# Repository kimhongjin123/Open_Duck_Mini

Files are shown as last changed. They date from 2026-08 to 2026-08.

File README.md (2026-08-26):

# Open Duck Mini v2

<table>
  <tr>
    <td> </td>
    <td> </td>
    <td> </td>
   </tr> 
</table>

## Fork addition: MiniDuck IO Shield

This fork adds a custom Raspberry Pi Zero 2 W I/O shield designed for the Open Duck Mini prototype. The addition includes the complete KiCad 9 project, connector and GPIO mapping, BOM, schematic PDF, prototype manufacturing outputs, photos, and a hardware demonstration video.

**[Open the MiniDuck IO Shield documentation](hardware/miniduck-io-shield/README.md)**

<p align="center">
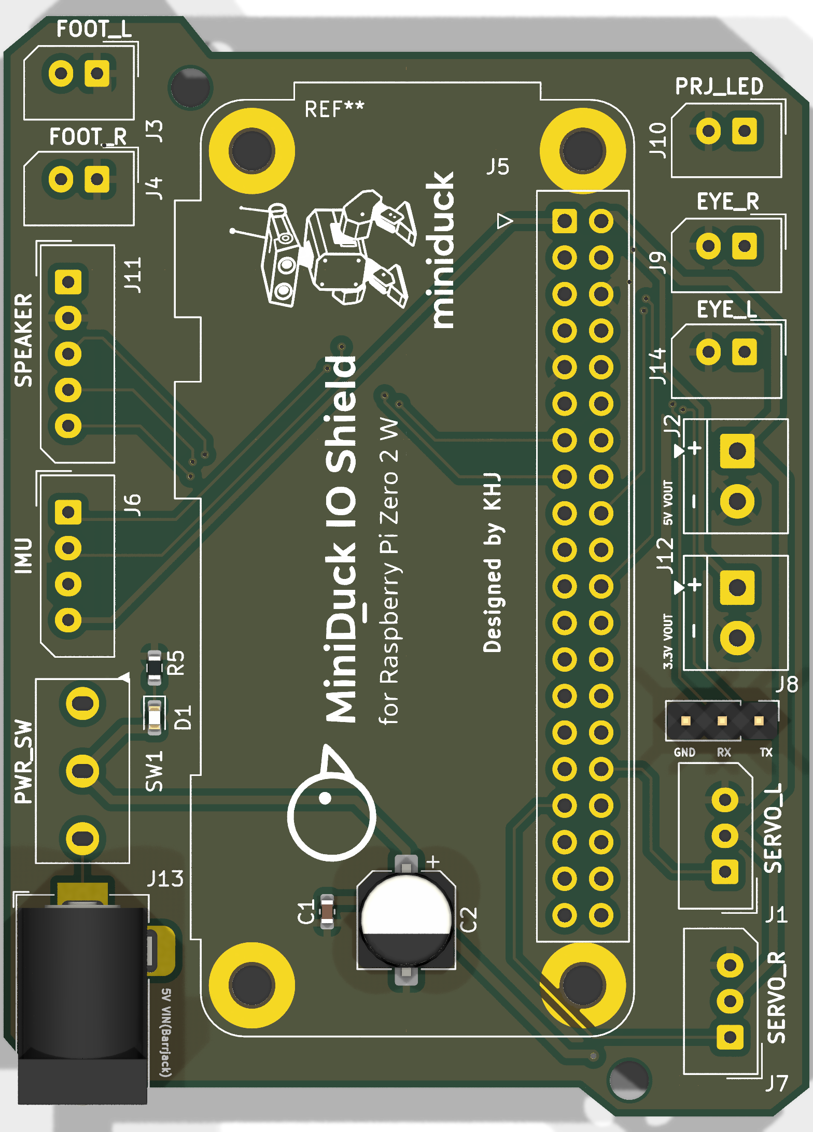
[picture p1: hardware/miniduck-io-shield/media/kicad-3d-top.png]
MiniDuck IO Shield top render
  
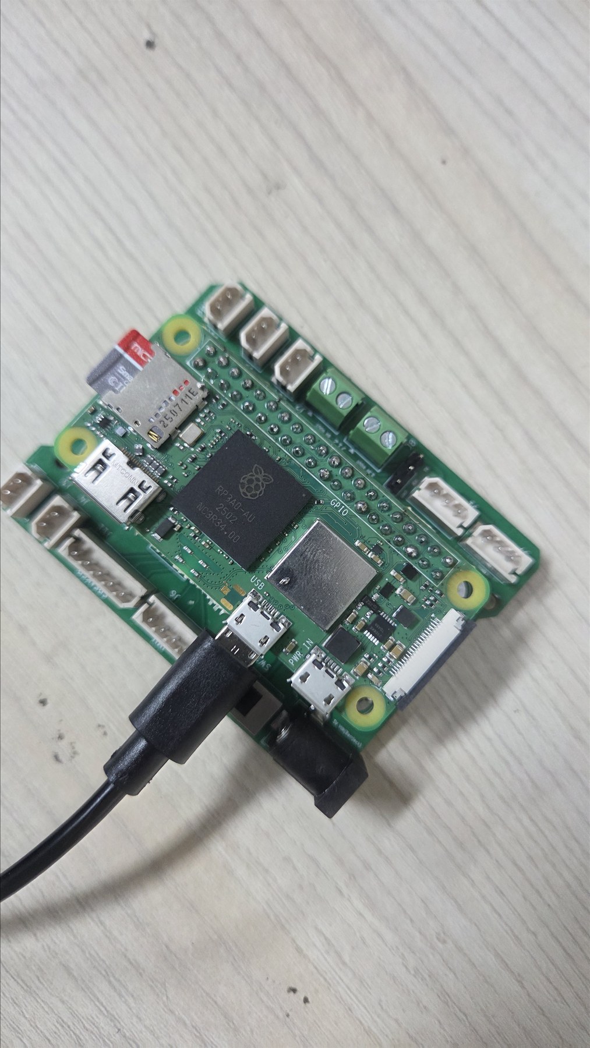
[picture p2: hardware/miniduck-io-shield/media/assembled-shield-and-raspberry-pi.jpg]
Assembled MiniDuck IO Shield with Raspberry Pi Zero 2 W
  
</p>

> [!IMPORTANT]
> This shield is a community hardware addition maintained in this fork; it is not part of the upstream Open Duck Mini design. Review the documented prototype warnings before fabrication.

We are making a miniature version of the BDX Droid by Disney. It is about 42 centimeters tall with its legs extended.
The full BOM cost should be under $400 !

This repo is kind of a hub where we centralize all resources related to this project. This is a working repo, so there are a lot of undocumented scripts :) We'll try to clean things up at some point.

# State of sim2real

https://github.com/user-attachments/assets/58721d0f-2f95-4088-8900-a5d02f41bba7

https://github.com/user-attachments/assets/4129974a-9d97-4651-9474-c078043bb182

https://github.com/user-attachments/assets/a0afcd38-15d8-40c6-8171-a619107406b8

# Updates

> Update 02/04/2024: You can try two policies we trained : [this one](BEST_WALK_ONNX.onnx) and [this one](BEST_WALK_ONNX_2.onnx)
> Run with the following arguments :
> python v2_rl_walk_mujoco.py --onnx_model_path ~/BEST_WALK_ONNX_2.onnx

> Update 15/03/2025: join our discord server to get help or show us your duck :) https://discord.gg/UtJZsgfQGe

> Update 07/02/2025: Big progress on sim2real, see videos above :)

> Update 24/02/2025: Working hard on sim2real ! 

> Update 07/02/2025 : We are writing documentation on the go, but the design and BOM should not change drastically. Still missing the "expression" features, but they can be added after building the robot!

> Update 22/01/2025 : The mechanical design is pretty much finalized (fixing some mistakes here and there). The current version does not include all the "expression" features we want to include in the final robot (LEDs for the eyes, a camera, a speaker and a microphone). We are now working on making it walk with reinforcement learning !

# Community 

duck_collage

Join our discord community ! https://discord.gg/UtJZsgfQGe

# CAD

https://cad.onshape.com/documents/64074dfcfa379b37d8a47762/w/3650ab4221e215a4f65eb7fe/e/0505c262d882183a25049d05

See [this document](docs/prepare_robot.md) for getting from a onshape design to a simulated robot in MuJoCo (Warning, outdated. Has not been updated in a while)

# RL stuff

We are switching to Mujoco Playground, see this [repo](https://github.com/apirrone/Open_Duck_Playground)

https://github.com/user-attachments/assets/037a1790-7ac1-4140-b154-2c901d20d5f5

## Reference motion generation for imitation learning 

https://github.com/user-attachments/assets/4cb52e17-99a5-47a8-b841-4141596b7afb

See [this repo](https://github.com/apirrone/Open_Duck_reference_motion_generator)

## Actuator identification 

We used Rhoban's [BAM](https://github.com/Rhoban/bam)

# BOM

https://docs.google.com/spreadsheets/d/1gq4iWWHEJVgAA_eemkTEsshXqrYlFxXAPwO515KpCJc/edit?usp=sharing

Chinese: https://zihao-ai.feishu.cn/wiki/AfAtw69vRigXaRk5UkbcrAiLnJw?from=from_copylink

# Build Guide

> New : you can now use the Tnkr guide ! https://tnkr.ai/explore/docs/open-duck-mini/open-duck-mini-v2#home

Chinese: https://zihao-ai.feishu.cn/wiki/space/7488517034406625281

## Print Guide

See [print_guide](docs/print_guide.md).

## Assembly Guide

See [assembly guide (incomplete)](docs/assembly_guide.md).

# Embedded runtime

This repo contains the code to run the policies on the onboard computer (Raspberry pi zero 2w) https://github.com/apirrone/Open_Duck_Mini_Runtime

# Training your own policies

If you want to train your own policies, and contribute to making the ducks walk nicely, see [this document](docs/sim2real.md)

> Thanks a lot to HuggingFace and Pollen Robotics for sponsoring this project !

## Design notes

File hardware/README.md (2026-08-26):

# Hardware additions

This directory contains hardware developed in this fork and kept separate from the upstream Open Duck Mini files.

- [MiniDuck IO Shield](miniduck-io-shield/README.md) - Raspberry Pi Zero 2 W carrier and I/O breakout for the robot prototype.

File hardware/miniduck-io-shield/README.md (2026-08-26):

# MiniDuck IO Shield

A two-layer Raspberry Pi Zero 2 W shield that consolidates power distribution and the Open Duck Mini prototype's servo, foot-switch, IMU, speaker, UART, and LED connections.

MiniDuck IO Shield top render

This is a fork-specific community hardware addition, designed by KHJ and kept separate from the upstream Open Duck Mini design. The board has been fabricated, assembled with a Raspberry Pi Zero 2 W, and exercised on the robot prototype shown below.

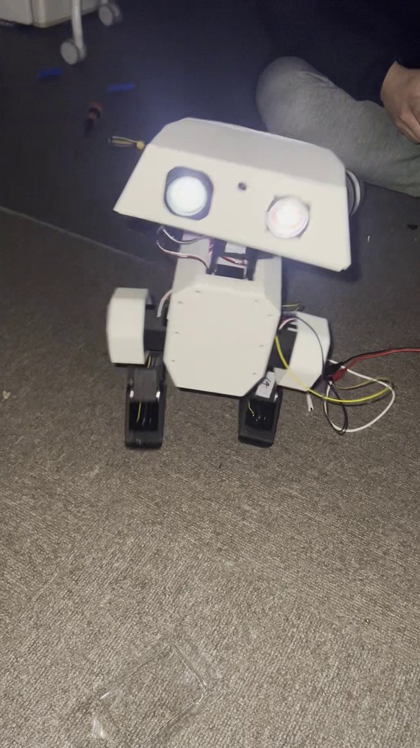
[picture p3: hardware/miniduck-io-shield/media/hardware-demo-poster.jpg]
Open Duck Mini hardware demonstration


The linked demonstration is a 46.9-second, 1080 x 1920 HEVC MP4. A [five-frame contact sheet](media/hardware-demo-contact-sheet.jpg) is also available for quick viewing.

## Board summary

| Item | Detail |
| --- | --- |
| Controller | Raspberry Pi Zero 2 W, 40-pin GPIO header |
| PCB | 2 layers, 1.6 mm nominal thickness |
| Outline | Approximately 56.0 x 76.5 mm bounding box |
| Input power | 5 V barrel-jack input through onboard slide switch |
| Power outputs | 5 V and 3.3 V screw-terminal breakouts |
| Robot I/O | 2 servo, 2 foot-switch, I2C IMU, I2S speaker, UART, and 3 LED outputs |
| Main connector families | 2.50 mm Molex SPOX, 3.50 mm screw terminals, 2.54 mm pin/IDC headers |
| Design tool | KiCad 9; outputs regenerated with KiCad 9.0.4 |
| Status | Fabricated and assembled prototype; see validation notes before reuse |

## Repository contents

| Path | Contents |
| --- | --- |
| [`kicad/`](kicad/) | Editable schematic, PCB, and project files |
| [`CONNECTORS.md`](CONNECTORS.md) | Connector pinout and Raspberry Pi GPIO mapping |
| [`docs/bom.csv`](docs/bom.csv) | BOM exported from the schematic |
| [`docs/schematic.pdf`](docs/schematic.pdf) | Single-page schematic for quick review |
| [`docs/drc-report.json`](docs/drc-report.json) | KiCad PCB rule-check report |
| [`docs/erc-report.json`](docs/erc-report.json) | KiCad schematic rule-check report |
| [`manufacturing/`](manufacturing/) | Prototype Gerbers, drill files, maps, and a vendor-upload ZIP |
| [`media/`](media/) | Renders, PCB/layout photos, assembly photos, robot photo, and demo video |

The original KiCad basename, `miniduc_shild`, is preserved so the project opens without disrupting its existing file relationships. Local KiCad state, caches, and automatic backups are intentionally excluded.

## Photos

| Fabricated board | Assembled shield |
| --- | --- |
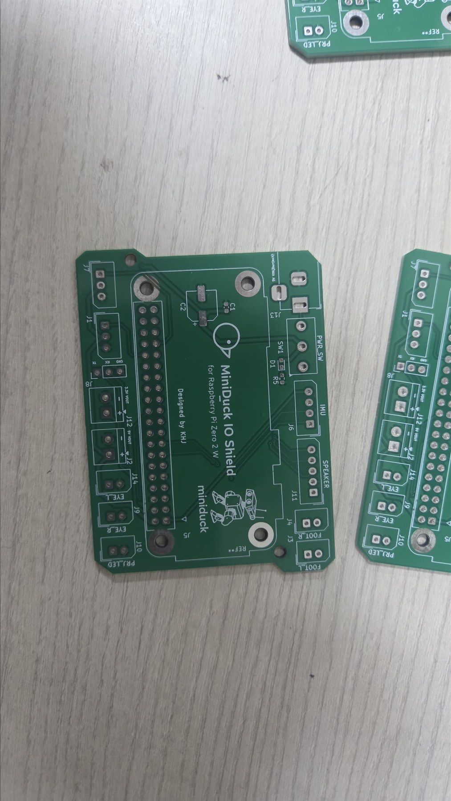
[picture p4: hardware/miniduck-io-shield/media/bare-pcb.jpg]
Fabricated MiniDuck IO Shield
|  | Assembled shield and Raspberry Pi Zero 2 W |

| PCB layout | Robot prototype |
| --- | --- |
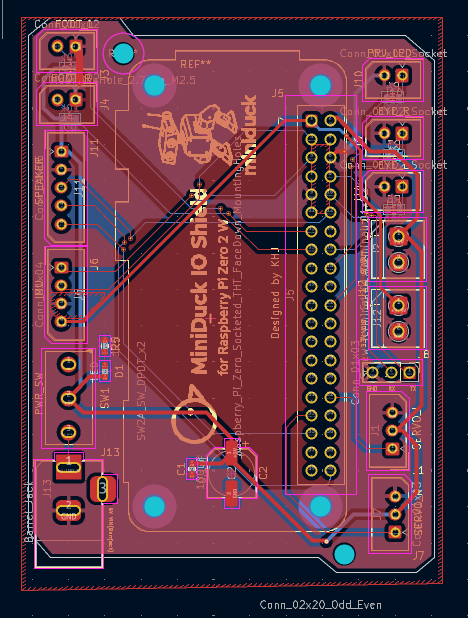
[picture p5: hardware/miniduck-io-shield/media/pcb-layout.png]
MiniDuck IO Shield PCB layout
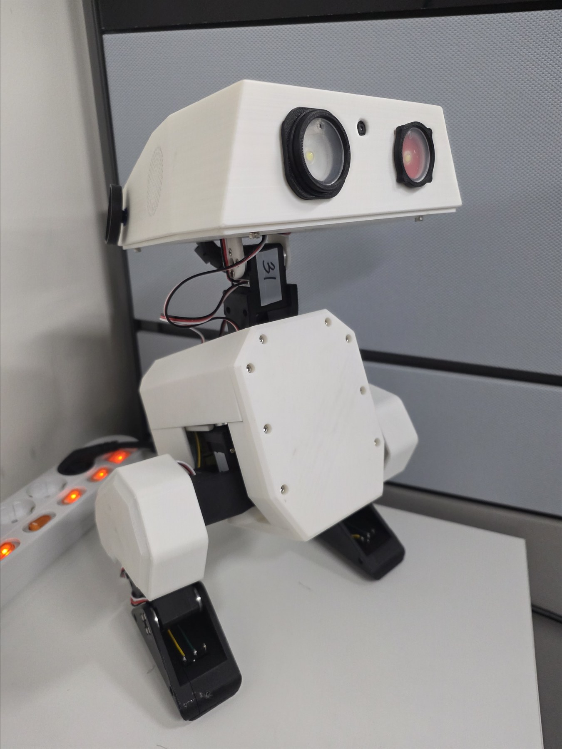
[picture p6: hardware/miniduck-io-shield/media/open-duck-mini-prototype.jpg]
Open Duck Mini robot prototype
|  |  |

## Important prototype notes

- The three LED connector silkscreen labels do not match the electrical nets. Follow the actual-net mapping in [`CONNECTORS.md`](CONNECTORS.md), not the nearby label alone.
- KiCad reports no error-severity ERC/DRC items, but it does report warnings. The exact counts and categories are recorded in [`VALIDATION.md`](VALIDATION.md).
- R1 is a 10 kOhm resistor assigned to a `C_0603_1608Metric` library footprint. The land pattern is 0603-sized, but the library assignment should be corrected in a future revision.
- The custom slide-switch footprint name may not exist in another user's local library. Its placed footprint geometry is embedded in the PCB file.
- The manufacturing package is a reproducible snapshot of this fabricated prototype, not a claim that the design has passed an independent production review.

## Opening and regenerating

1. Open `kicad/miniduc_shild.kicad_pro` in KiCad 9.
2. Review the schematic and PCB against the intended wiring and connector orientation.
3. Run ERC and DRC locally and inspect every warning.
4. Regenerate Gerbers and drill files from the reviewed PCB before ordering a revised batch.

This folder follows the repository's root [Apache-2.0 license](../../LICENSE).

## 한국어 요약

이 폴더는 Raspberry Pi Zero 2 W 기반 Open Duck Mini용 I/O 실드보드 작업을 정리한 것입니다. KiCad 원본, 핀맵, BOM, 회로도 PDF, 시제품 제조 파일, 제작·조립 사진과 구동 영상을 포함합니다. 현재 파일은 실제 제작된 프로토타입 기록이며, LED 커넥터 실크 인쇄와 실제 GPIO 연결이 서로 다르므로 재사용하거나 재발주하기 전에 반드시 [`CONNECTORS.md`](CONNECTORS.md)와 [`VALIDATION.md`](VALIDATION.md)를 확인해야 합니다.

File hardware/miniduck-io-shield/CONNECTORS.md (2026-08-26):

# Connector and GPIO map

Pin numbers below come from the KiCad schematic/netlist. Verify physical orientation from the footprint's pin-1 marker before connecting hardware.

## External connectors

| Ref | Board function / nearby silkscreen | Pin mapping |
| --- | --- | --- |
| J1 | SERVO_L | 1: GPIO12 / servo L signal; 2: +5 V; 3: GND |
| J2 | 5V VOUT | 1: +5 V; 2: GND |
| J3 | FOOT_L | 1: GND; 2: GPIO22 / foot L input |
| J4 | FOOT_R | 1: GND; 2: GPIO27 / foot R input |
| J5 | Raspberry Pi 40-pin header | See the GPIO table below |
| J6 | IMU | 1: GPIO3 / I2C SCL1; 2: GPIO2 / I2C SDA1; 3: GND; 4: +3.3 V |
| J7 | SERVO_R | 1: GPIO13 / servo R signal; 2: +5 V; 3: GND |
| J8 | UART | 1: GPIO15 / UART RX; 2: GPIO14 / UART TX; 3: GND |
| J9 | Nearby silkscreen: EYE_R | 1: through R3 (220 Ohm) to GPIO24 / LED_L; 2: GND |
| J10 | Nearby silkscreen: PRJ_LED | 1: through R4 (220 Ohm) to GPIO25 / LED_R; 2: GND |
| J11 | SPEAKER | 1: +5 V; 2: GND; 3: GPIO18 / I2S BCLK; 4: GPIO21 / I2S DOUT; 5: GPIO19 / I2S LRCLK |
| J12 | 3.3V VOUT | 1: +3.3 V; 2: GND |
| J13 | 5V VIN barrel jack | 1: switched 5 V input through SW1; 2: GND |
| J14 | Nearby silkscreen: EYE_L | 1: through R6 (220 Ohm) to GPIO23 / LED_PRJ; 2: GND |

> [!CAUTION]
> J9, J10, and J14 have a confirmed silkscreen-to-net mismatch in this revision. Electrically, J9 is LED_L, J10 is LED_R, and J14 is LED_PRJ. Use the electrical mapping above.

## Raspberry Pi header signals used

| Physical pin | Net / function |
| ---: | --- |
| 1 | +3.3 V |
| 2 | +5 V |
| 3 | GPIO2 / I2C SDA1 |
| 5 | GPIO3 / I2C SCL1 |
| 6 | GND |
| 8 | GPIO14 / UART TX |
| 9 | GND |
| 10 | GPIO15 / UART RX |
| 12 | GPIO18 / I2S BCLK |
| 13 | GPIO27 / foot R |
| 15 | GPIO22 / foot L |
| 16 | GPIO23 / projector LED |
| 18 | GPIO24 / left-eye LED |
| 22 | GPIO25 / right-eye LED |
| 32 | GPIO12 / servo L |
| 33 | GPIO13 / servo R |
| 35 | GPIO19 / I2S LRCLK |
| 40 | GPIO21 / I2S DOUT |

All other J5 positions are unconnected in the shield schematic.

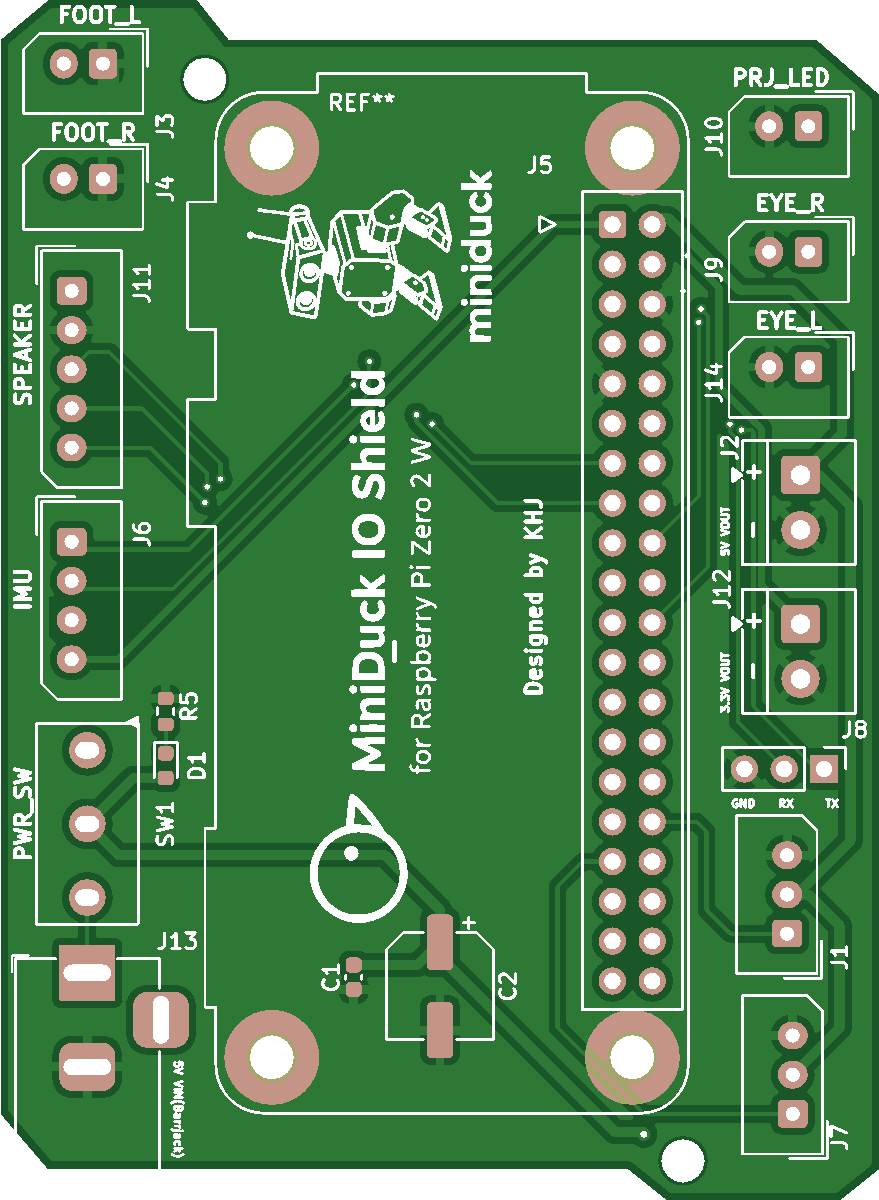
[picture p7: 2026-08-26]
hardware/miniduck-io-shield/media/pcb-render.png

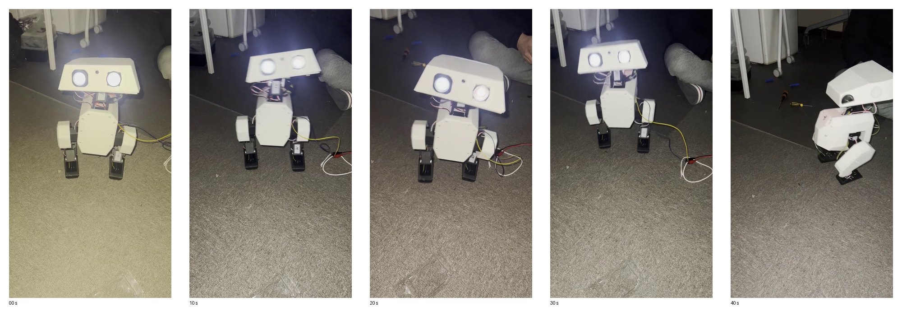
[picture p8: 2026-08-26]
hardware/miniduck-io-shield/media/hardware-demo-contact-sheet.jpg

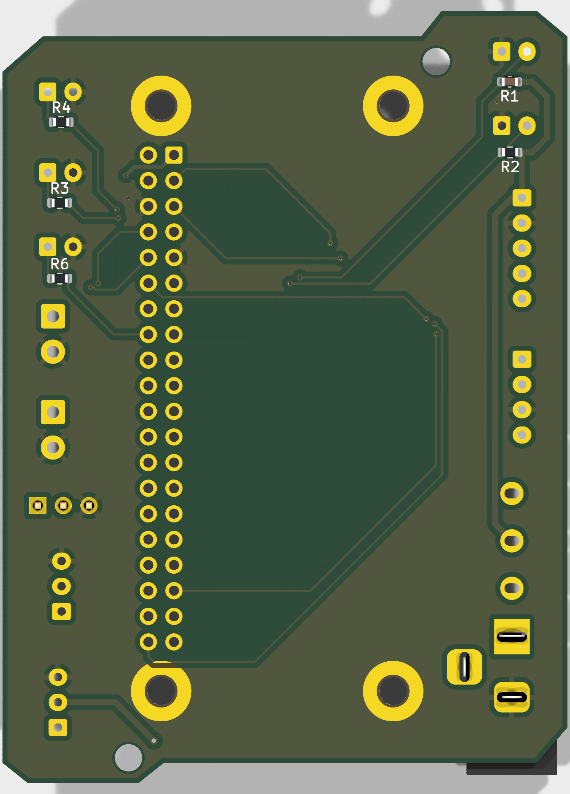
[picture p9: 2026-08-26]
hardware/miniduck-io-shield/media/kicad-3d-bottom.png

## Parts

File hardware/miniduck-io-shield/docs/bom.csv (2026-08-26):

Refs | Value | Footprint | Qty | DNP
C1 | 0.1uF | Capacitor_SMD:C_0603_1608Metric | 1
C2 | 100uF | Capacitor_SMD:CP_Elec_6.3x5.3 | 1
D1 | LED | LED_SMD:LED_0603_1608Metric | 1
J1 | Servo_L | Connector_Molex:Molex_SPOX_5267-03A_1x03_P2.50mm_Vertical | 1
J2,J12 | Screw_Terminal_01x02 | TerminalBlock_4Ucon:TerminalBlock_4Ucon_1x02_P3.50mm_Horizontal | 2
J3,J4 | Conn_01x02 | Connector_Molex:Molex_SPOX_5267-02A_1x02_P2.50mm_Vertical | 2
J5 | Conn_02x20_Odd_Even | Connector_IDC:IDC-Header_2x20_P2.54mm_Latch6.5mm_Vertical | 1
J6 | Conn_01x04 | Connector_Molex:Molex_SPOX_5267-04A_1x04_P2.50mm_Vertical | 1
J7 | Conn_01x03 | Connector_Molex:Molex_SPOX_5267-03A_1x03_P2.50mm_Vertical | 1
J8 | Conn_01x03 | Connector_PinHeader_2.54mm:PinHeader_1x03_P2.54mm_Vertical | 1
J9,J10,J14 | Conn_01x02_Socket | Connector_Molex:Molex_SPOX_5267-02A_1x02_P2.50mm_Vertical | 3
J11 | Conn_01x05 | Connector_Molex:Molex_SPOX_5267-05A_1x05_P2.50mm_Vertical | 1
J13 | Barrel_Jack | Connector_BarrelJack:BarrelJack_Horizontal | 1
R1 | 10k | Capacitor_SMD:C_0603_1608Metric | 1
R2 | 10k | Resistor_SMD:R_0603_1608Metric | 1
R3,R4,R6 | 220 | Resistor_SMD:R_0603_1608Metric | 3
R5 | 120 | Resistor_SMD:R_0603_1608Metric | 1
SW1 | SW2A_SW_DPDT_x2 | wowmecha:SW_Slide_SPDT_PBS110G | 1

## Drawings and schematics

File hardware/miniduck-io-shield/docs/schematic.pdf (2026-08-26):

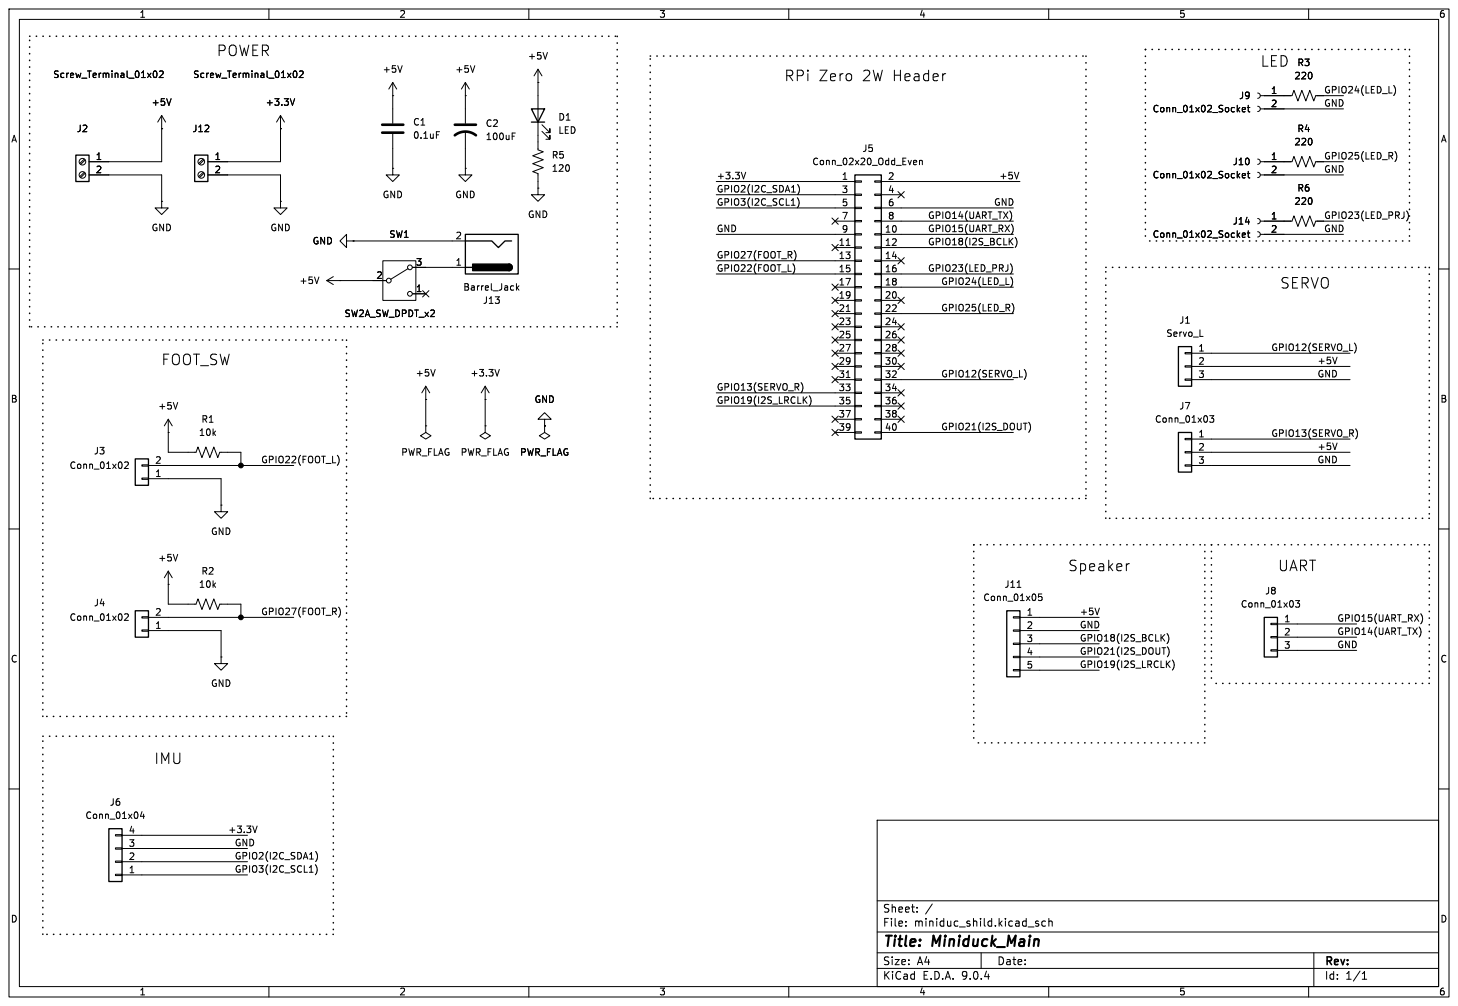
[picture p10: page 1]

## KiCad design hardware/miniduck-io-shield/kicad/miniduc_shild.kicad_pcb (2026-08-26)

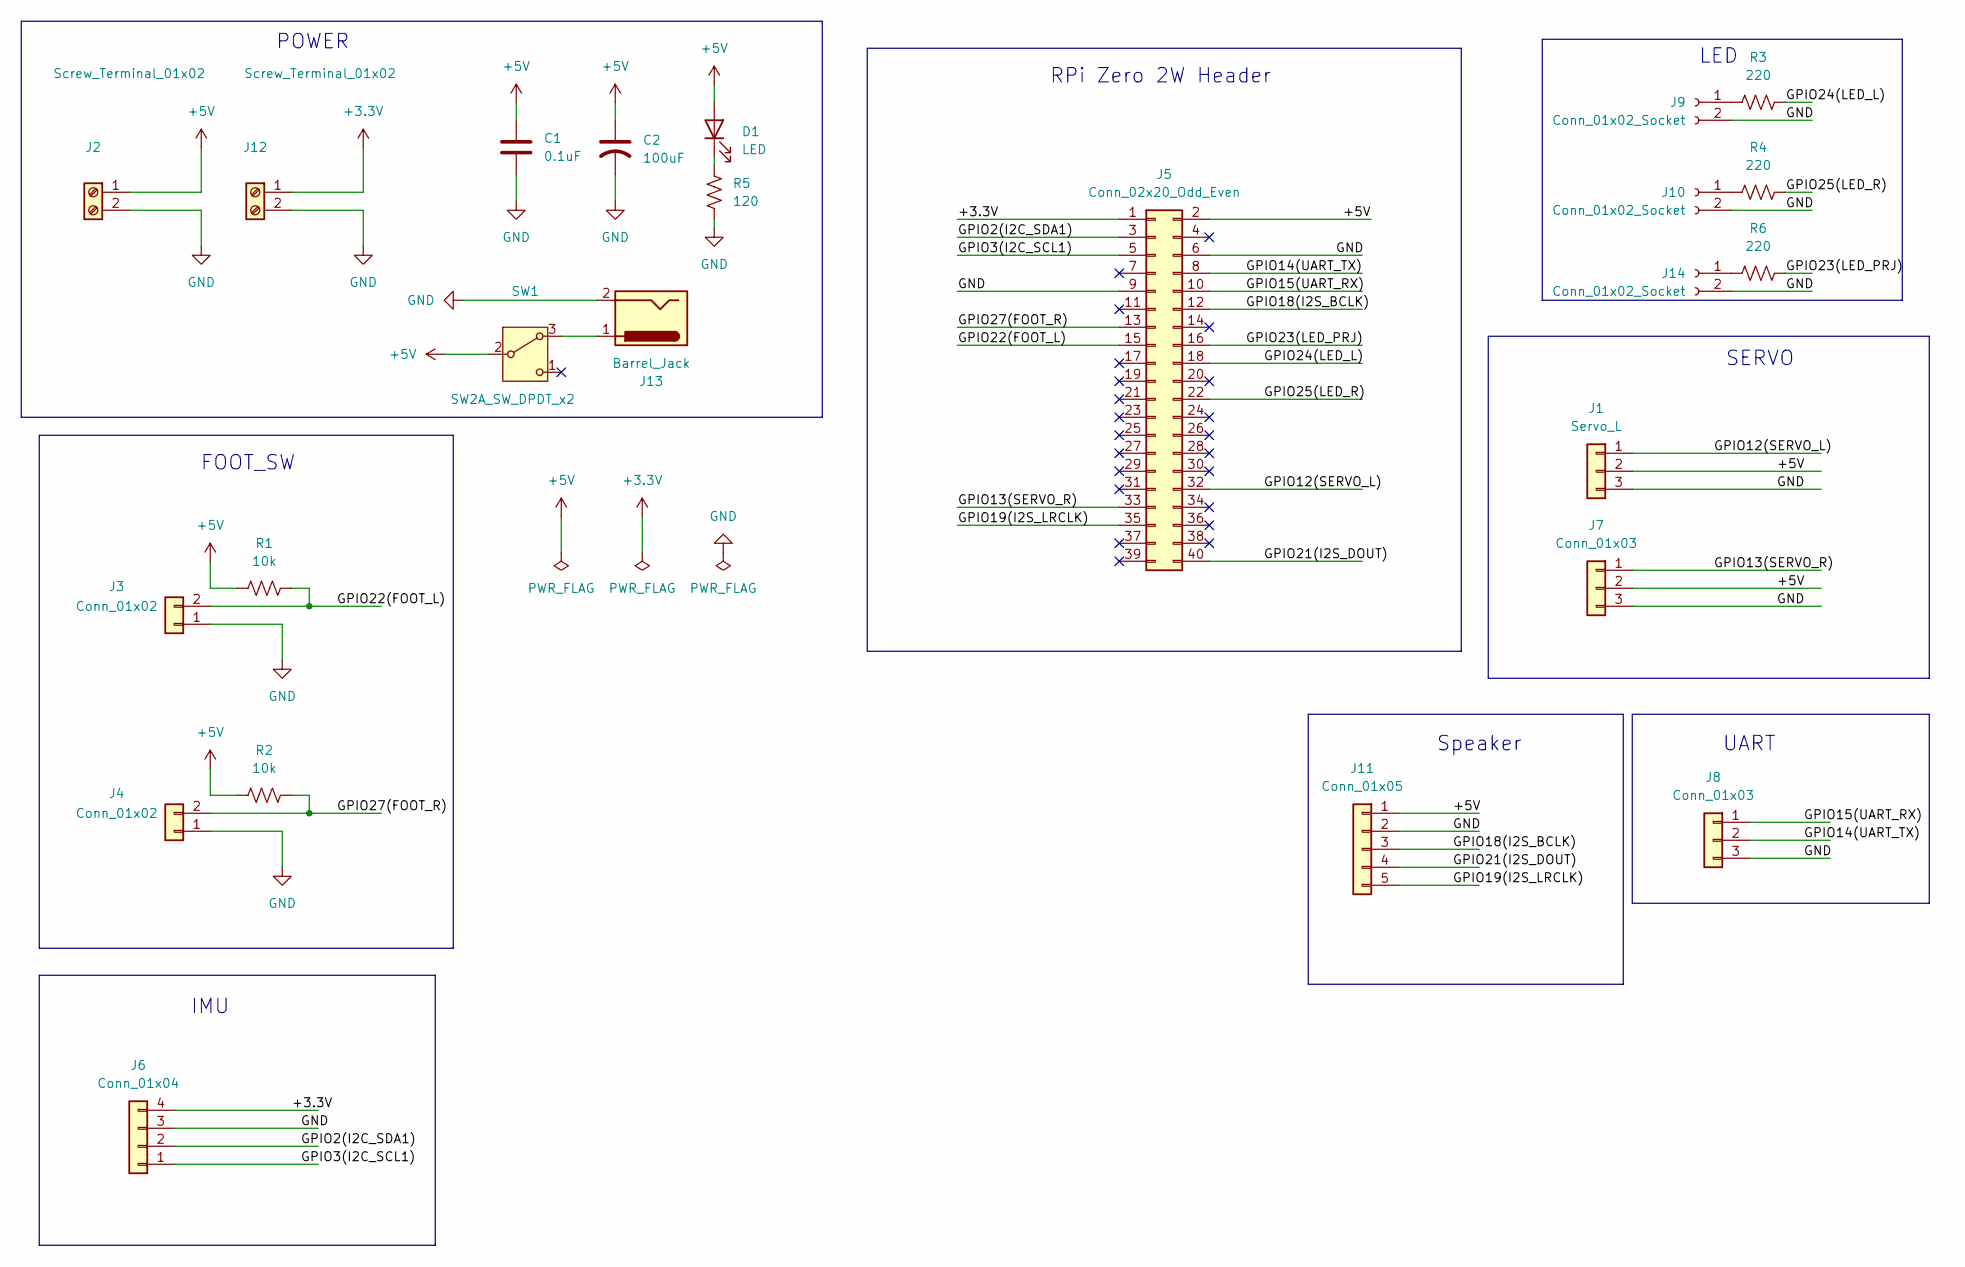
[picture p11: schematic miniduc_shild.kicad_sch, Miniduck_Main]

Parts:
C1: 0.1uF; C_0603_1608Metric
C2: 100uF; CP_Elec_6.3x5.3
D1: LED; LED_0603_1608Metric
J1: Servo_L; Molex_SPOX_5267-03A_1x03_P2.50mm_Vertical
J2, J12: Screw_Terminal_01x02; TerminalBlock_4Ucon_1x02_P3.50mm_Horizontal
J3, J4: Conn_01x02; Molex_SPOX_5267-02A_1x02_P2.50mm_Vertical
J5: Conn_02x20_Odd_Even; IDC-Header_2x20_P2.54mm_Latch6.5mm_Vertical
J6: Conn_01x04; Molex_SPOX_5267-04A_1x04_P2.50mm_Vertical
J7: Conn_01x03; Molex_SPOX_5267-03A_1x03_P2.50mm_Vertical
J8: Conn_01x03; PinHeader_1x03_P2.54mm_Vertical
J9, J10, J14: Conn_01x02_Socket; Molex_SPOX_5267-02A_1x02_P2.50mm_Vertical
J11: Conn_01x05; Molex_SPOX_5267-05A_1x05_P2.50mm_Vertical
J13: Barrel_Jack; BarrelJack_Horizontal
R1: 10k; C_0603_1608Metric
R2: 10k; R_0603_1608Metric
R3, R4, R6: 220; R_0603_1608Metric
R5: 120; R_0603_1608Metric
SW1: SW2A_SW_DPDT_x2; SW_Slide_SPDT_PBS110G

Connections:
+3.3V: J5.1, J6.4, J12.1
+5V: C1.2, C2.1, D1.2 (A), J1.2, J2.1, J5.2, J7.2, J11.1, R1.1, R2.1, SW1.2 (B)
/GPIO2(I2C_SDA1): J5.3, J6.2
/GPIO3(I2C_SCL1): J5.5, J6.1
/GPIO12(SERVO_L): J1.1, J5.32
/GPIO13(SERVO_R): J5.33, J7.1
/GPIO14(UART_TX): J5.8, J8.2
/GPIO15(UART_RX): J5.10, J8.1
/GPIO18(I2S_BCLK): J5.12, J11.3
/GPIO19(I2S_LRCLK): J5.35, J11.5
/GPIO21(I2S_DOUT): J5.40, J11.4
/GPIO22(FOOT_L): J3.2, J5.15, R1.2
/GPIO23(LED_PRJ): J5.16, R6.2
/GPIO24(LED_L): J5.18, R3.2
/GPIO25(LED_R): J5.22, R4.2
/GPIO27(FOOT_R): J4.2, J5.13, R2.2
GND: C1.1, C2.2, J1.3, J2.2, J3.1, J4.1, J5.6, J5.9, J6.3, J7.3, J8.3, J9.2, J10.2, J11.2, J12.2, J13.2, J14.2, R5.2
unnamed: D1.1 (K), R5.1
unnamed: J9.1, R3.1
unnamed: J10.1, R4.1
unnamed: J14.1, R6.1
unnamed: J13.1, SW1.3 (A)

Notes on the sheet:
POWER
UART
RPi Zero 2W Header
FOOT_SW
LED
IMU
SERVO
Speaker

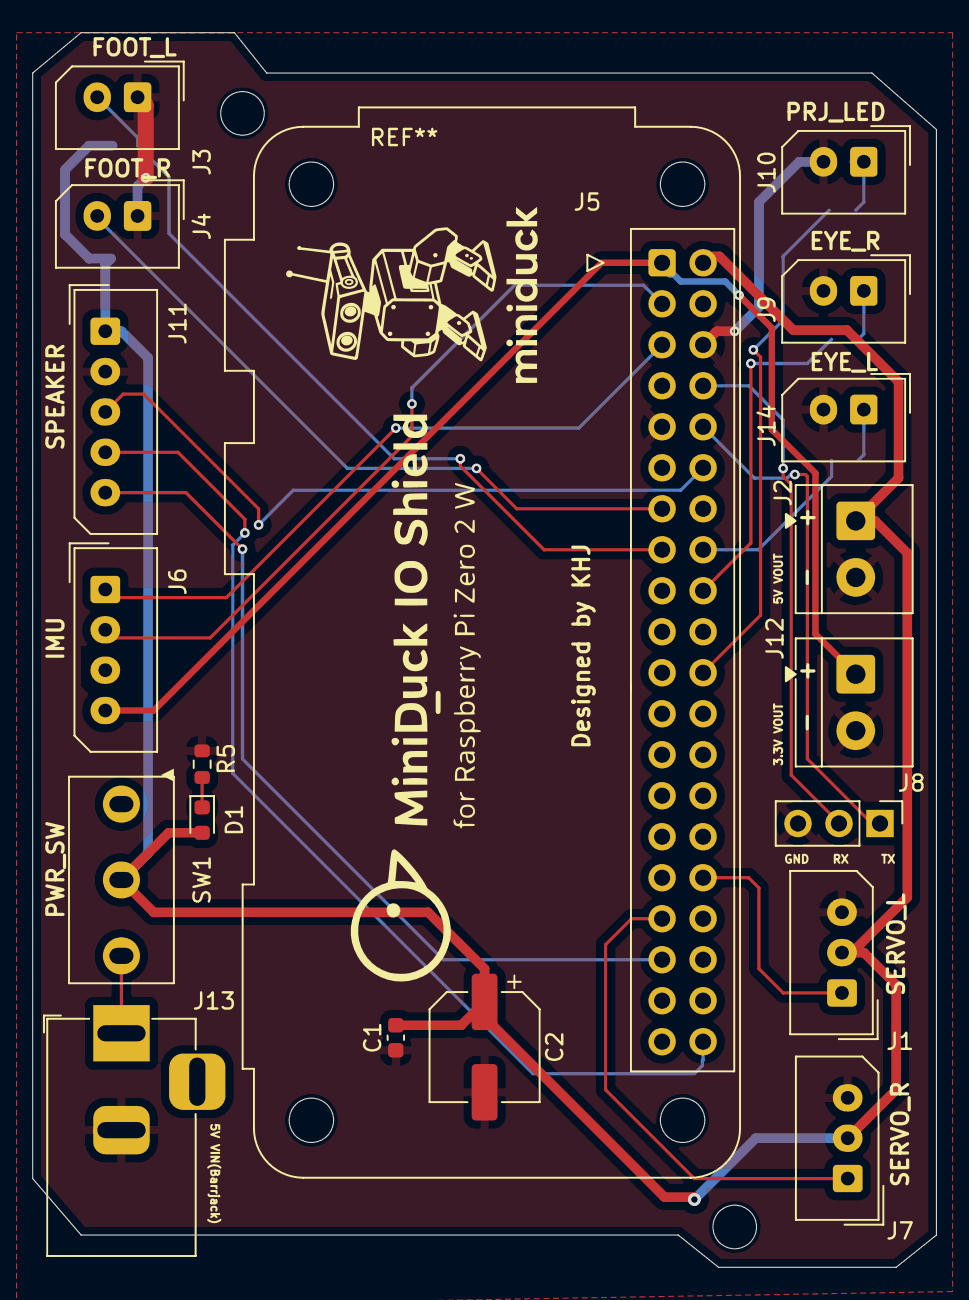
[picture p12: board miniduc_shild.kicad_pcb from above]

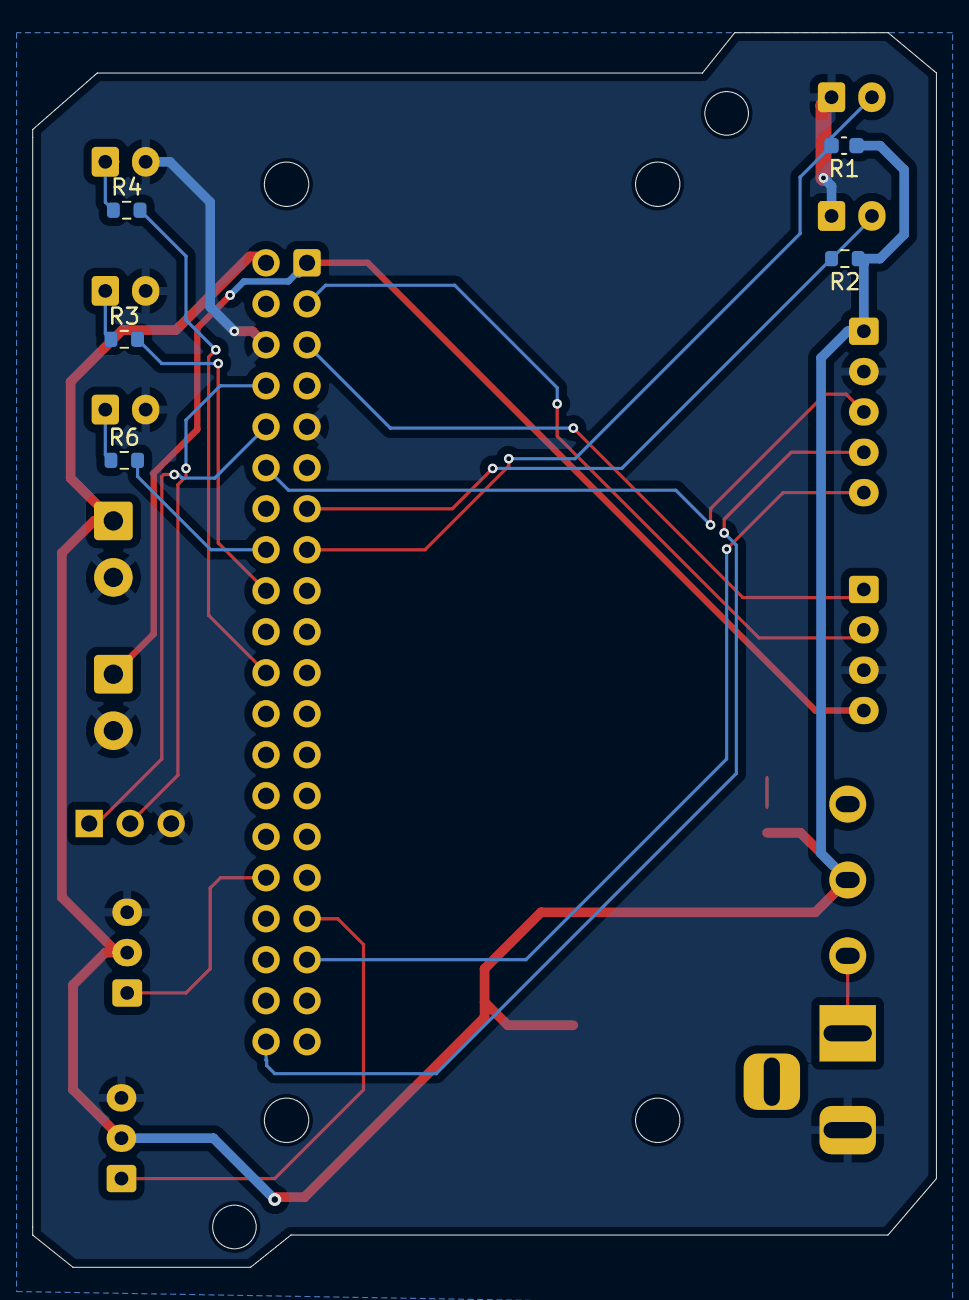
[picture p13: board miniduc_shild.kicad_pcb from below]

Board: 2 copper layers, 56.0 x 76.5 mm, 26 parts (5 on the bottom side), 22 nets.

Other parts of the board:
-: LOGO
Designed by KHJ: LOGO

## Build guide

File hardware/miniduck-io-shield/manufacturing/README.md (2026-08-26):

# Prototype manufacturing outputs

These files were regenerated from `../kicad/miniduc_shild.kicad_pcb` with KiCad CLI 9.0.4.

- [`gerbers/`](gerbers/) contains front/back copper, mask, paste, silkscreen, board outline, Gerber job file, PTH/NPTH drills, and drill maps.
- [`miniduck-io-shield-gerbers.zip`](miniduck-io-shield-gerbers.zip) packages the same set for convenient vendor upload.

The board is a fabricated prototype with documented DRC warnings. Read [`../VALIDATION.md`](../VALIDATION.md) and verify the Gerber preview, stack-up, drill sizes, connector orientation, and vendor rules before placing an order.

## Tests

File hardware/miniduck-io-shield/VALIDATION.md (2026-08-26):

# Validation record

The source snapshot was checked and regenerated with KiCad CLI 9.0.4 on 2026-08-26. These results document the existing fabricated prototype; they do not replace an engineering review.

## Export results

- Schematic PDF: generated successfully.
- BOM: generated successfully.
- Top and bottom 3D renders: generated successfully.
- Gerber and PTH/NPTH drill outputs: generated successfully.

## ERC

- Error-severity items: 0
- Warning-severity items: 35
- All 35 warnings are `unconnected_wire_endpoint` items in the schematic.

Review each endpoint in KiCad before editing or reusing the circuit. The warnings are retained in [`docs/erc-report.json`](docs/erc-report.json).

## PCB DRC

- Error-severity items: 0
- Warning-severity items: 12
- Unconnected PCB items: 0
- Schematic-parity warnings: 2

The 12 PCB warnings consist of:

- 2 silkscreen-to-board-edge clearance warnings near J13.
- 2 placed-footprint/library-copy mismatch warnings for J5 and the Raspberry Pi reference footprint.
- 6 minimum silkscreen text-height warnings.
- 2 silkscreen-over-solder-mask warnings around J5.

The two schematic-parity warnings are extra mechanical/reference footprints without normal schematic components. Full machine-readable details are retained in [`docs/drc-report.json`](docs/drc-report.json).

## Known design-review items

1. Correct the J9/J10/J14 LED silkscreen labels or the connector/net assignment so physical labels and electrical functions agree.
2. Change R1's footprint library assignment from the capacitor library to the matching 0603 resistor footprint.
3. Resolve or intentionally exclude the ERC wire-endpoint warnings.
4. Review the J13 silkscreen/edge clearance and all small silkscreen text against the selected PCB vendor's rules.
5. Confirm the custom SW1 footprint and the physical orientation of every polarized/pin-1 component before ordering.
